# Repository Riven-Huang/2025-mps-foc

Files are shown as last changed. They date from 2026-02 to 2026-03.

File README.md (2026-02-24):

# MPS-FOC 开源电机驱动

<div align="center">



[]()
[]()

**基于 TI C2000 F28002x 的三环 FOC 电机驱动**

</div>

## 📋 项目简介

本项目依托于 2025 MPS“智驱未来”机器人芯动力设计挑战赛 并使用MPS旗下系列IC制作电源、驱动和传感器，使用 TI TMS320F280023C 单片机的开源 FOC（磁场定向控制）电机驱动项目。支持有传感器（磁编码器）FOC 闭环控制，提供电流环、速度环、位置环三环级联控制。

目前借助开环电压模式已实现 **速度环** 和 **位置环** 的运行，经验证控制效果良好。在硬件设计上，有预留好供 **电流环** 使用的A、C相电流采样，代码中同样给出了参数整定方法与完整架构。不过若只想复现该项目测试视频中的效果，可以将其电流环删去，简要复现。

### 🔑 核心特性

- **FOC 算法**： Clarke/Park 变换 + SVPWM（带3次谐波注入）
- **三环控制**：电流环(20kHz) → 速度环(2kHz) → 位置环(1kHz)
- **位置传感器**：MA600 磁编码器（13-bit分辨率，4096 PPR）
- **功率驱动**：MP6539 三相 MOSFET 预驱动
- **接口丰富**：支持 UART 调试（可扩展 CAN/RS485）

---

## 🏗️ 硬件说明

### 📦 硬件实物图

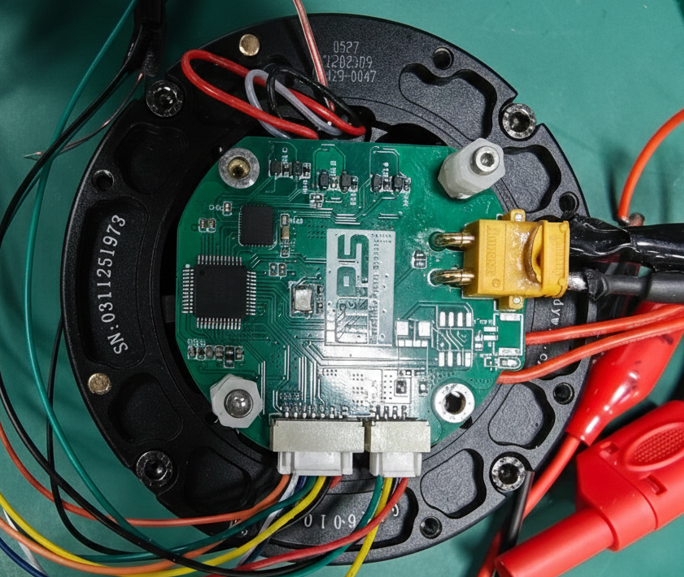
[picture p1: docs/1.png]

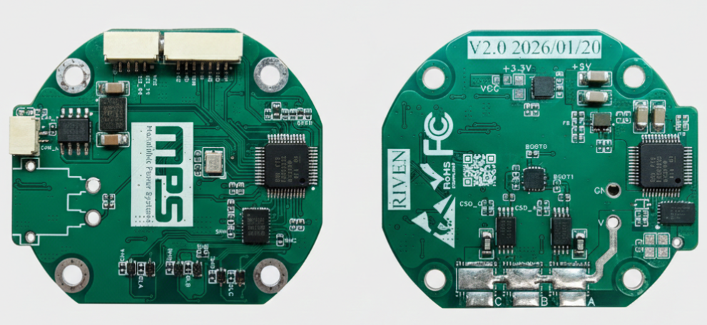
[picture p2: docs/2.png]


### 📦 主要器件

| 器件 | 型号 | 说明 |
|---|---|---|
| MCU | TMS320F280023C | 32-bit C2000，100MHz 主频 |
| 驱动IC | MP6539 | 三相无刷电机预驱动 |
| 编码器 | MA600A | 磁编码器，13-bit 分辨率 |
| 功率MOS | BSC030N08NS5 | 低导通电阻 N-MOS |

### 🔌 引脚定义

```
PWM 输出:  EPWM1A (GPIO0) → A相
           EPWM2A (GPIO2) → B相
           EPWM3A (GPIO4) → C相

电流采样:  ADCINA11 (Ia)
           ADCINB7 (Ic)
           ADCINA5 (Vbus)

MA600A编码器:   GPIO33 (CS)
               GPIO32 (CLK)
               GPIO24 (MOSI)
               GPIO16 (MISO)

控制信号:  GPIO31 (nSLEEP)
           GPIO12 (FAULT)
```

### 📐 电气参数

| 参数 | 数值 |
|---|---|
| 输入电压 | 48V±5% DC |
| 峰值电流 | 4A |
| 持续电流 | 1.5A |
| PWM 频率 | 20kHz |
| 最大转速 | 4000 RPM |

---

## 📂 目录结构

```
mps-foc-opensource/
├── program/                    # 固件源码
│   ├── foc_main.c              # 主程序 + 中断控制
│   ├── app/
│   │   ├── foc_core.c/h        # FOC 核心算法
│   │   ├── soft_spi_ma600.c/h # 磁编码器软SPI驱动
│   │   └── bsp_tim.c/h        # 定时器驱动
│   ├── device/                 # TI C2000 器件库
│   ├── cmd/                    # 链接器配置文件
│   └── c2000.syscfg           # TI SysConfig 配置
├── circuit/                    # 硬件设计
│   ├── PCB_MPS-FOC_V2.1.pdf   # PCB 丝印图
│   └── SCH_MPS-FOC_V2.1.pdf  # 原理图
├── manufacture/                # 制造文件 (Gerber)
│   └── MPS-FOC_V2.1/          # 嘉立创可直接下单
├── LICENSE                     # 许可证文件
└── README.md                   # 本文件
```

---

## 💻 软件说明

### 🌀 三环控制逻辑

| 环 | 频率 | 输入 | 输出 | 作用 |
|----|---|---|---|---|
| 电流环 | 20kHz | Id/Iq 误差 | Vd/Vq | 快速响应，抑制电流波动 |
| 速度环 | 2kHz | 速度误差 | Iq_Ref | 稳态精度，动态响应 |
| 位置环 | 1kHz | 位置误差 | Speed_Ref | 位置跟踪，高精度控制 |

### ⚙️ 参数配置

在 `foc_main.c` 中修改以下参数：

#### 1. 电机参数

```c
// 电机参数
#define POLE_PAIRS      14      // 极对数
#define PWM_PERIOD      2500    // PWM周期 (20kHz @ 50MHz)
#define GEAR_RATIO      8.0f    // 减速比
```

#### 2. 电流环参数 (根据带宽计算)

电流环使用 PI 控制器，参数可根据 desired bandwidth 自动计算：

```c
// 电机参数
float control_freq = 20000;              // 控制频率 20kHz
float singlephase_R = 1.45f/2.0f;       // 单相电阻 (Ω)
float singlephase_L = 0.823f/2.0f/1000; // 单相电感 (H)

// 电流环带宽 (建议设为采样频率的1/10~1/20，即 1kHz~2kHz)
float current_bandwidth = 1000.0f;       // 电流环带宽 (Hz)

// PI 参数计算公式:
// Ti = L/R (积分时间常数)
// Kp = L * ωc (比例增益)
// Ki = R * ωc (积分增益)
// 其中 ωc = 2π * fc (交叉频率)
float current_Ti = singlephase_L / singlephase_R;       // 积分时间
float current_wc = 2.0f * 3.14159f * current_bandwidth; // 交叉频率
float current_Kp = singlephase_L * current_wc;          // 比例增益
float current_Ki = singlephase_R * current_wc;          // 积分增益
```

#### 3. 速度环/位置环参数

```c
// 速度环 (2kHz)
pid_spd.Kp = 0.1f; pid_spd.Ki = 0.005f; pid_spd.OutMax = VOLTAGE_LIMIT;

// 位置环 (1kHz)
pid_pos.Kp = 20.0f; pid_pos.Ki = 0.0f; pid_pos.OutMax = 500.0f;
```

> **提示**: 调整 `current_bandwidth` 可改变电流环响应速度。带宽越高，响应越快，但对噪声越敏感。

---

## 🚀 快速开始

### 🛠️ 开发环境

- **IDE**: TI CCS (Code Composer Studio) 12.x
- **SDK**: C2000Ware 6.00.01+
- **编译器**: TI C2000 Clang v3.x

### 🔌 硬件连接

```
┌─────────────────┐         ┌─────────────────┐
│   FOC 驱动板    │         │    电机模组     │
│                 │         │                 │
│  A+  ───────────┼─────────▶│   A相 (橙)     │
│  B+  ───────────┼─────────▶│   B相 (黄)     │
│  C+  ───────────┼─────────▶│   C相 (绿)     │
│  GND ──────────┼─────────▶│   GND (黑)     │
│                 │         │                 │
└─────────────────┘         └─────────────────┘
```

### 🎮 运行步骤

1. **上电初始化**
   - 系统自动进行电流零点校准（1秒）
   - 校准完成后进入编码器对齐阶段（1秒）
   - 对齐完成后进入闭环控制

2. **选择控制模式**

   | 模式 | Control_Mode 值 | 说明 |
   |------|-----------------|------|
   | 力矩模式 | 0 | 直接给定电压 |
   | 速度模式 | 1 | 给定目标转速 |
   | 位置模式 | 2 | 给定目标角度 |

3. **调试接口**

   通过 CCS 调试窗口修改变量：

   ```c
   Run_Flag = 1;           // 启动 PWM 输出
   Control_Mode = 1;       // 切换到速度模式
   User_Speed_Ref = 500;  // 设置目标转速 500 RPM
   ```

### 🔧 调试步骤（快速检查表）

| 步骤 | 内容 | 验证方法 |
|:---:|---|---|
| 1 | **硬件检查** | 测 3.3V / 12V / 48V / LED正常亮起 |
| 2 | **程序烧录** | 检查ADC中断，定时器中断能否正常运行 |
| 3 | **PWM 测试** | 示波器查看三相 PWM + 死区时间 |
| 4 | **ADC 校准** | 断开电流，零点应在 2048 附近 |
| 5 | **编码器** | 旋转电机，观察角度变化 |
| 6 | **开环电压模式** | `Control_Mode=0`，`User_Iq_Ref=1` 电机转动|
| 7 | **速度环** | `Control_Mode=1`，`User_Speed_Ref=100` |
| 8 | **位置环** | `Control_Mode=2`，`User_Pos_Ref=3.14` |

### 调试变量速查

```c
Run_Flag = 1;           // 1=开启PWM, 0=关闭
Control_Mode = 0;       // 0=电压/1=速度/2=位置
User_Iq_Ref = 1.0f;    // 电压模式输入 (V)
User_Speed_Ref = 100;   // 速度模式输入 (RPM)
User_Pos_Ref = 3.14;   // 位置模式输入 (Rad)
MA600_dir = 1.0f;      // 编码器方向，取反改 -1
```

### 常见问题

| 问题 | 解决方法 |
|---|---|
| 电机不转/异响 | 交换 A/B/C 相序 |
| 只朝一个方向转 | `MA600_dir = -1` |
| 电流采样异常 | 检查运放偏置、调整 `CURRENT_SCALE` |
| 速度波动大 | 调小 `Speed_Filter_K` 或调整 PID |

---

## 📖 使用教程

### 电机参数整定

1. **电流环参数整定(暂无)**
   - 测试阶段用较小初值尝试
   - 测试完成后，用计算公式整定

2. **速度环参数整定**
   - 电流环稳定后，切换到速度模式
   - 给定小目标速度（如 100 RPM）
   - 整定方法同上
   - 推荐初值：Kp=0.1, Ki=0.005

3. **位置环参数整定**
   - 最后整定位置环，仅用Kp

### 🔧 常见问题

**Q1: 电机不转，有异响**

> 检查：
> 1. 尝试更换A,B,C三相相序任意两根
> 2. 尝试修改编码器极性
> 3. PWM 输出是否正常

---

## 📄 许可证

本项目采用 [CERN-OHL-S v2](LICENSE) 开源许可证。

CERN-OHL-S 是硬件开源的标准许可证，要求衍生作品必须以相同条款开源。

---

## 📧 联系我们

- 问题反馈：GitHub Issues
- 邮箱：banzang_coder@163.com

---

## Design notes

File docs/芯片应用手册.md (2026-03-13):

# MPS-FOC 芯片应用手册

## 1. 项目评审结论

当前项目已经形成完整的“电源链路 + 驱动链路 + 角度反馈链路”：`48V -> 12V -> 5V -> 3.3V` 分级供电稳定，`MP6539B` 三相驱动链路可正常出 PWM，`MA600A` 角度反馈已接入 FOC 主环，速度环和位置环可运行，电流环参数也已经在代码中按带宽法计算并初始化。对比赛场景来说，这套方案的优势是启动快、可复现性高、展示稳定。

---

## 2. 本项目中的 MPS 芯片分工

1. `MA600A`：电机角度反馈（FOC 位置基准）
2. `MP6539B`：三相栅极驱动（驱动 6 颗外置 MOS）
3. `MP4583`：`48V -> 12V` 高压 Buck
4. `MPM3632S`：`12V -> 5V` Buck 电源模块
5. `MP20051`：`5V -> 3.3V` 低噪声 LDO
6. `MIE1W0505`：隔离 `5V -> ISO_5V`（通信隔离侧）

---

## 3. 分芯片应用说明（含数据与项目落地）

### 3.1 MA600A（位置传感）

MA600A 是本项目 FOC 的角度基准，固件在 `20kHz` 中断里通过软 SPI 读角度（`MA600_ReadRaw_Fast()`），并用 `theta = raw * (2π/65536)` 转机械角，当前实现的角度量化步进是 `0.00009587 rad`（`0.00549°`）；再乘电机 `14` 极对得到电角度，等效电角分辨率 `0.0769°`。这个分辨率级别在低速下能明显减少 Park 变换输入抖动，速度环/位置环会更平顺，尤其是小角度定位时更容易“贴着目标走”。

### 3.2 MP6539B（3 相栅极驱动）

驱动芯片承担“把 MCU 的控制量变成三相功率级开关动作”的核心角色，项目中由 EPWM 输出 `6` 路互补 PWM（A/B/C 三相上下桥）送入 MP6539B，再去驱动外置 `6` 颗 BSC030N08NS5；按器件数据（同系列口径）可覆盖 `8V~100V` 驱动电压范围，栅极驱动能力约 `IOH=800mA`、`IOL=1A`、`6` 路驱动通道。固件里 `nSLEEP` 由 GPIO 直接控制，上电后先使能再放 PWM，且 MCU 侧已配置死区：`deadband=100` 计数（`100MHz` TBCLK 下约 `1us`），这套配置对比赛调试非常友好，既能快速跑起来，也有明确保护边界。

### 3.3 MP4583（48V -> 12V 高压 Buck）

MP4583 把母线 `48V` 先降到 `12V`，直接把高压与控制/接口电源域隔开；发布版原理图参数是 `R6=180k`、`R5=12.58k`、`L6=22uH`，按常见 FB 公式 `Vout = VFB * (1 + Rtop/Rbot)`、`VFB≈0.8V` 计算：`Vout ≈ 0.8*(1+180/12.58)=12.25V`，与目标 12V 一致。把最高压这一级先处理掉后，后级 5V/3.3V 电源设计压力会明显降低，比赛现场电池波动时系统也更稳。

### 3.4 MPM3632S（12V -> 5V 电源模块）

MPM3632S 是中间母线电源，承担全板 `5V` 供电主力；器件本身是集成电感降压模块，典型能力 `4V~18V` 输入、`3A` 输出、`2.2MHz` 开关频率。项目原理图给出的分压是 `R35=43k`、`R36=8.2k`，按 `VFB≈0.8V` 计算得到 `Vout ≈ 4.99V`，与 5V 目标精确对齐。这个模块把外围设计复杂度压低了，硬件迭代时间更短，适合比赛周期内快速出稳定板。

### 3.5 MP20051（5V -> 3.3V LDO）

MP20051 是控制侧“末级净化电源”，给 MCU 与逻辑域提供更干净的 3.3V；器件参数层面有 `1A` 输出能力、`PSRR=63dB@1kHz`、`Dropout=140mV@1A`、噪声约 `13uVrms`，在 FOC 的 ADC 采样与角度处理场景里很实用。原理图分压为 `R42=75k`、`R41=24k`，按 `Vout = 0.8*(1+75/24)` 可得约 `3.3V`。此外 LDO 热设计可直接按 `P=(Vin-Vout)*Iout` 估算，例如 `5V->3.3V`、`0.2A` 时约 `0.34W`，比赛中按这个量级预留散热即可。

### 3.6 MIE1W0505（隔离电源）

MIE1W0505 给 CAN 隔离侧提供独立 `ISO_5V`，把功率地噪声和通信地做物理隔离；从型号可直接看出是 `5V->5V`、`1W` 隔离电源，折算输出电流上限约 `Iout_max = 1W / 5V = 0.2A`。这个隔离电源在电机大电流开关噪声环境下非常关键，通信链路不容易被功率回流“带脏”，长时间演示时总线稳定性明显更好。

---

## 4. 开关电源参数怎么计算（本项目可直接套用）

### 4.1 输出电压分压

```text
Vout = VFB * (1 + Rtop / Rbot)
```

1. `MP4583`（48V->12V）：`Rtop=180k, Rbot=12.58k`，`Vout≈12.25V`
2. `MPM3632S`（12V->5V）：`Rtop=43k, Rbot=8.2k`，`Vout≈4.99V`

### 4.2 占空比一阶估算

```text
D ≈ Vout / Vin
```

1. `48V -> 12V`：`D≈0.25`
2. `12V -> 5V`：`D≈0.417`

### 4.3 电感纹波电流估算（Buck）

```text
ΔIL = (Vin - Vout) * D / (L * fsw)
```

以 MP4583 级举例：若 `Vin=48V, Vout=12V, D=0.25, L=22uH`，假设 `fsw=500kHz`，则 `ΔIL≈0.82A`。这个值可用于反推电感和输出电容选型。

### 4.4 输出电容估算（纹波约束）

```text
Cout >= ΔIL / (8 * fsw * ΔVout)
```

延续上例，若目标纹波 `ΔVout=50mV`，则 `Cout>=4.1uF`（工程上通常会留余量并并联低 ESR 电容）。

### 4.5 LDO 功耗估算（MP20051）

```text
P_LDO = (Vin - Vout) * Iout
```

`5V -> 3.3V`、`Iout=0.2A` 时约 `0.34W`，可作为热设计和封装温升评估输入。

---

## 5. 代码中的关键实参（和芯片联动）

1. 控制频率：`20kHz`（`PWM_PERIOD=2500`，中心对齐）
2. 电流环带宽：`1000Hz`
3. 电流环 PI（按代码电机参数计算）：`Kp≈2.586`，`Ki≈4555`
4. 速度计算常数：`190985.9`（`20kHz * 60 / 2π`）
5. 总线电压换算：`Vbus = 0.01933594 * ADC`

这些值已经在工程中闭环使用，手册中的芯片参数计算与控制参数是同一套口径。

---

## 6. 评审备注（建议在比赛材料中说明）

项目工程文件中存在“同一电源网络的历史参数痕迹”（如原理图 PDF 与工程库可见不同分压组合），但两套参数都围绕 `12V/5V/3.3V` 目标设计。比赛提交前建议以“实板丝印+实测电压+BOM导出”为最终口径，把 `README`、`应用手册`、`答辩 PPT` 三处参数统一，评委追问时会更稳。

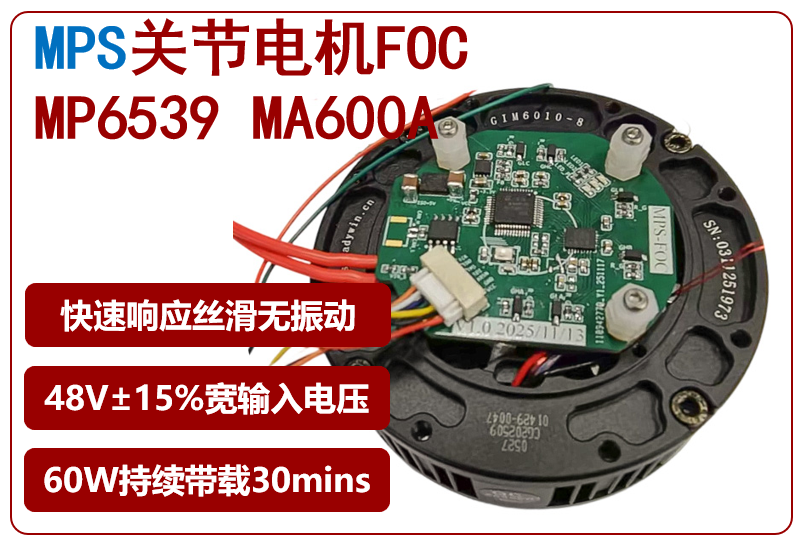
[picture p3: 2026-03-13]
产品图.png

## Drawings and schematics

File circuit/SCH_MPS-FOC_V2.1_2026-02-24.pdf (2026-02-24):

# 高压BUCK 48V->12V

TMS320F280023CPTS | BUCK 12V->5V

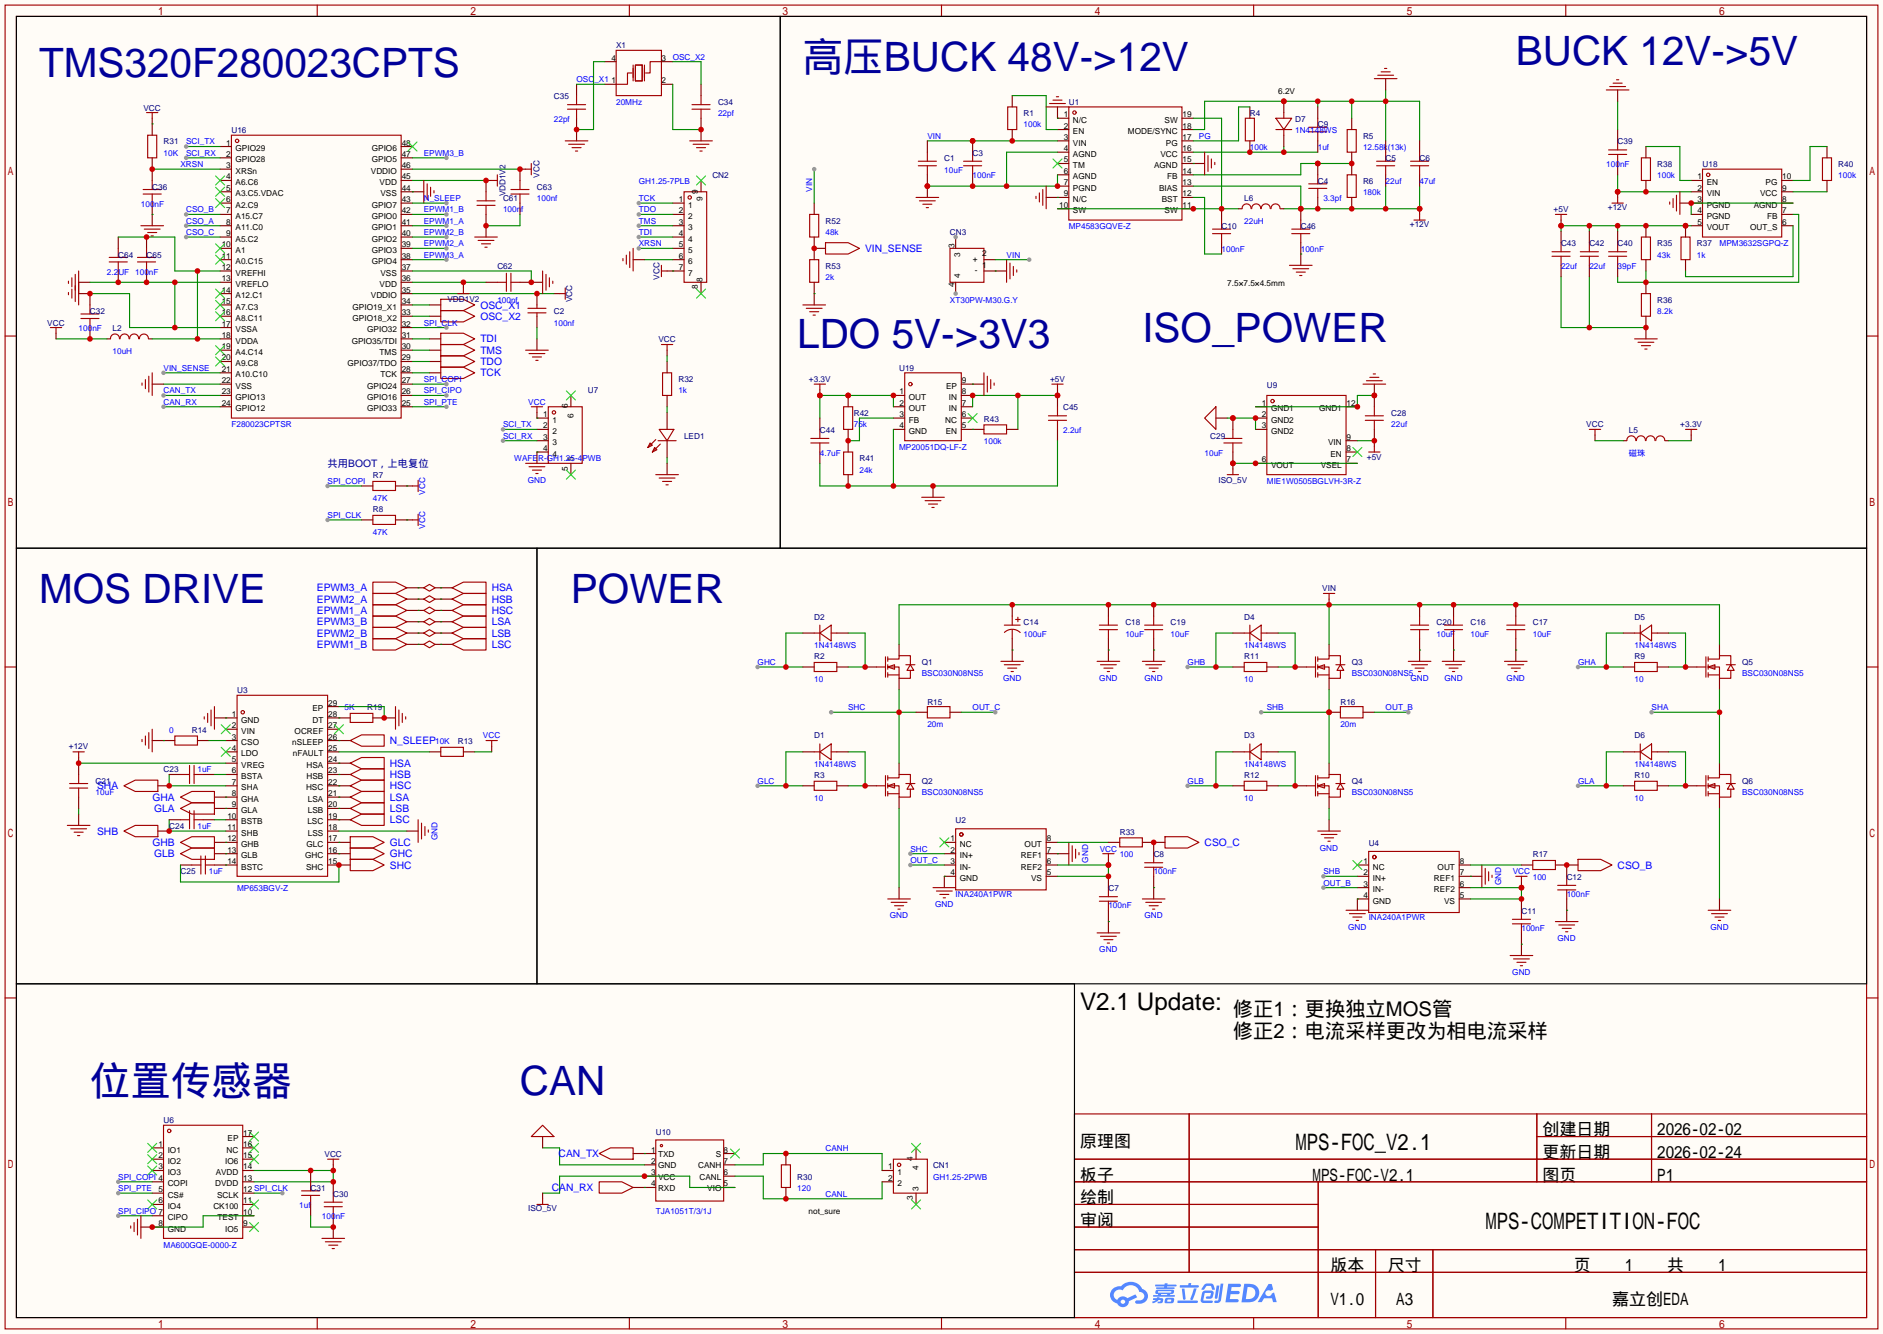
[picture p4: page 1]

TEST 10 CK100 11 SCLK 12 DVDD 13 AVDD 14 IO6 15 NC 16 EP 17

原理图 | MPS-FOC_V2.1 | 创建日期 | 2026-02-02

更新日期 | 2026-02-24

板子 | MPS-FOC-V2.1 | 图页 | P1
绘制 | | MPS-COMPETITION-FOC
审阅

V1.0 | A3 | 嘉立创EDA

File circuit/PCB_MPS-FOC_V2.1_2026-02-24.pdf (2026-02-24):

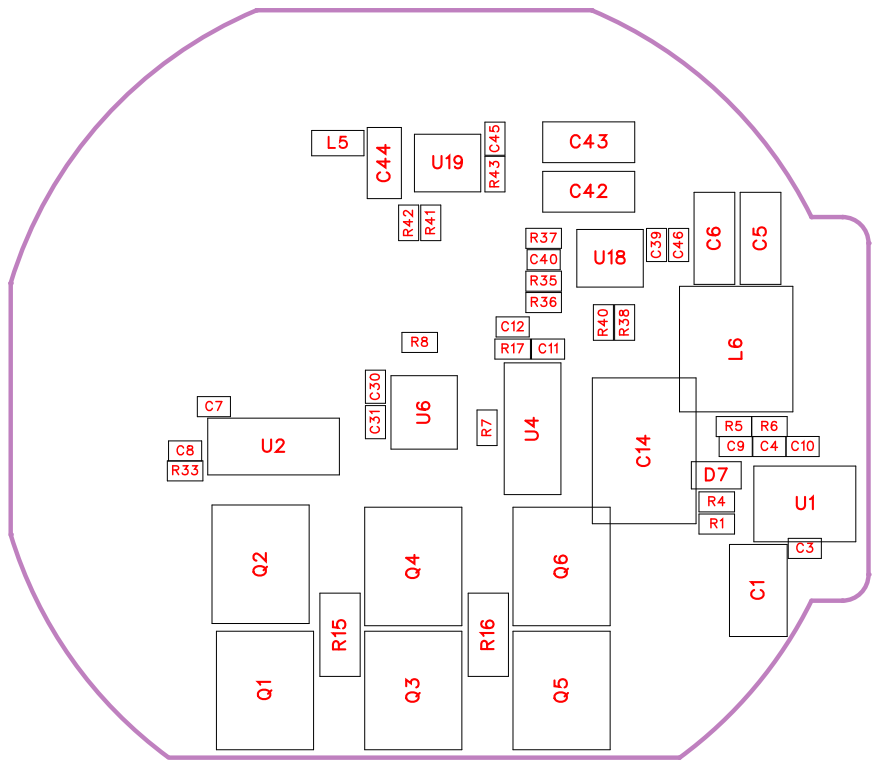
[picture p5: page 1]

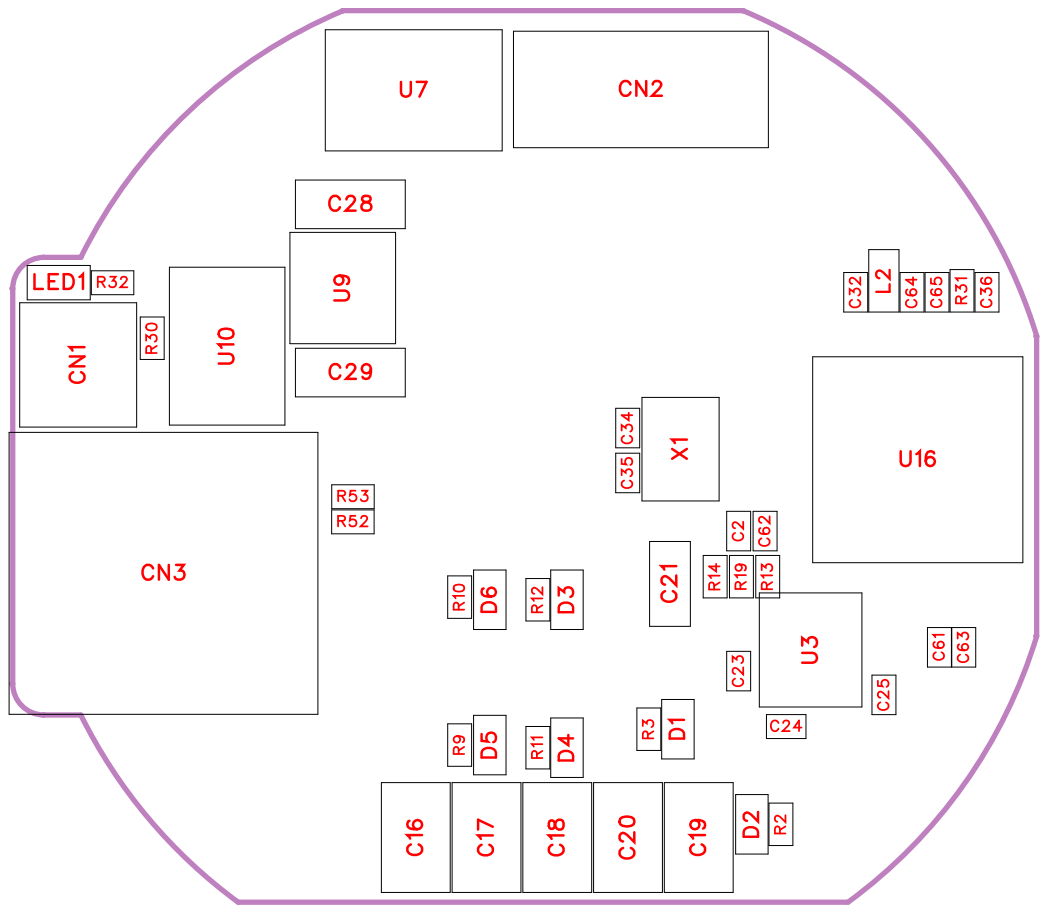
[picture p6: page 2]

No. | Quantity | Comment | Designator | Footprint | Value | Manufacturer Part | Manufacturer | Supplier Part | Supplier
1 | 6 | 10uF | C1,C16,C17,C18,C19,C20 | C1210 | 10uF | FS32X106K1 01EGG | PSA(信昌电 陶) | C5156756 | LCSC
2 | 1 | 100nf | C2 | C0402 | 100nf | 0402CG120J 500NT | FH(风华) | | LCSC
3 | 12 | 100nF | C3,C7,C8,C10,C11,C12,C3 0,C32,C36,C39,C46,C65 | C0402 | 100nF
4 | 1 | 3.3pf | C4 | C0402 | 3.3pf
5 | 4 | 22uf | C5,C28,C42,C43 | C1206 | 22uf | CL31A106KB HNNNE | SAMSUNG( 三星) | | LCSC
6 | 1 | 47uf | C6 | C1206 | 47uf | CL31A106KB HNNNE | SAMSUNG( 三星) | | LCSC
7 | 2 | 1uf | C9,C31 | C0402 | 1uf
8 | 1 | 100uF | C14 | CAP-TH_BD 10.0-P5.00-D 0.6-FD_H16. 0 | 100uF | ERA100V100 M10X16 | JIERR(捷而 瑞) | C49256825 | LCSC
9 | 1 | 10uF | C21 | C0805 | 10uF | CGA0805X5 R106K250M T | HRE(芯声) | C6119887 | LCSC
10 | 3 | 1uF | C23,C24,C25 | C0402 | 1uF
11 | 1 | 10uF | C29 | C1206 | 10uF | CL31A106KB HNNNE | SAMSUNG( 三星) | C13585 | LCSC
12 | 2 | 22pf | C34,C35 | C0402 | 22pf
13 | 1 | 39pF | C40 | C0402 | 39pF
14 | 1 | 4.7uF | C44 | C0805 | 4.7uF | CL21A475KA QNNNE | SAMSUNG( 三星) | C1779 | LCSC
15 | 1 | 2.2uf | C45 | C0402 | 2.2uf
16 | 3 | 100nf | C61,C62,C63 | C0402 | 100nf
17 | 1 | 2.2UF | C64 | C0402 | 2.2UF
18 | 1 | GH1.25-2PW B | CN1 | CONN-TH_2 P-P1.25_XU NPU_WAFE R-GH1.25-2P WB | | GH1.25-2PW B | XUNPU(讯普 ) | C3029377 | LCSC
19 | 1 | GH1.25-7PL B | CN2 | CONN-SMD_ 7P-P1.25_X UNPU_WAF ER-GH1.25-7 PLB | | GH1.25-7PL B | XUNPU(讯普 ) | C3029373 | LCSC
20 | 1 | XT30PW-M3 0.G.Y | CN3 | CONN-TH_X T30PW-M | | XT30PW-M3 0.G.Y | AMASS(艾迈 斯) | C431092 | LCSC
21 | 7 | 1N4148WS | D1,D2,D3,D4,D5,D6,D7 | SOD-323_L1 .7-W1.3-LS2. 5-FD | | 1N4148WS | R+O(宏嘉诚) | C7420319 | LCSC
22 | 1 | 10uH | L2 | L0603 | 10uH
23 | 1 | 磁珠 | L5 | L0603 | | 磁珠 | Sunlord(顺络 ) | C1002 | LCSC

24 | 1 | 22uH | L6 | IND-SMD_L6 .0-W6.0 | 22uH | FNR6045S22 0MT | cjiang(长江微 电) | C168080 | LCSC
25 | 1 | LTST-C191K SKT | LED1 | LED0603-RD -YELLOW | | LTST-C191K SKT | LITEON(光宝 ) | C125100 | LCSC
26 | 6 | BSC030N08 NS5 | Q1,Q2,Q3,Q4,Q5,Q6 | nmos qfn封装
27 | 5 | 100k | R1,R4,R38,R40,R43 | R0402 | 100k
28 | 6 | 10 | R2,R3,R9,R10,R11,R12 | R0402 | 10
29 | 1 | 12.58k(13k) | R5 | R0402 | 12.58k(13k)
30 | 1 | 180k | R6 | R0402 | 180k
31 | 2 | 47K | R7,R8 | R0402 | 47K
32 | 2 | 10K | R13,R31 | R0402 | 10K
33 | 1 | 0 | R14 | R0402 | 0
34 | 2 | 20m | R15,R16 | R1206 | 20m | JER1206F1R 020 | JIERR(捷而 瑞) | C46634440 | LCSC
35 | 2 | 100 | R17,R33 | R0402 | 100 | 0402WGF20 03TCE | UNI-ROYAL( 厚声) | | LCSC
36 | 1 | 5K | R19 | R0402 | 5K
37 | 1 | 120 | R30 | R0402 | 120
38 | 2 | 1k | R32,R37 | R0402 | 1k
39 | 1 | 43k | R35 | R0402 | 43k
40 | 1 | 8.2k | R36 | R0402 | 8.2k
41 | 1 | 24k | R41 | R0402 | 24k
42 | 1 | 75k | R42 | R0402 | 75k
43 | 1 | 48k | R52 | R0402 | 48k
44 | 1 | 2k | R53 | R0402 | 2k
45 | 1 | MP4583GQV E-Z | U1 | QFN-19_L5.0 -W3.0_CD45 83GQVE | | MP4583GQV E-Z | MPS(芯源) | C29073231 | LCSC
46 | 2 | INA240A1P WR | U2,U4 | TSSOP-8_L4 .4-W3.0-P0.6 5-LS6.4-BL | | INA240A1P WR | TI(德州仪器) | C93965 | LCSC
47 | 1 | MP653BGV-Z | U3 | QFN-28_L5.0 -W4.0-P0.50-TL-EP3.7 | | MP653BGV-Z | MPS(芯源) | C5676243 | LCSC
48 | 1 | MA600GQE-0000-Z | U6 | WQFN-16_L 3.0-W3.0-P0. 50-BL-EP1.6 5 | | MA600GQE-0000-Z | MPS(芯源) | C18221548 | LCSC
49 | 1 | WAFER-GH1 .25-4PWB | U7 | CONN-SMD_ 4P-P1.25_X UNPU_WAF ER-GH1.25-4 PWB | | WAFER-GH1 .25-4PWB | XUNPU(讯普 ) | C3029379 | LCSC

50 | 1 | MIE1W0505 BGLVH-3R-Z | U9 | LGA-12_L4.0 -W5.0_MIE1 W0505BGLV H | | MIE1W0505 BGLVH-3R-Z | MPS(芯源 ) | C22419841 | LCSC
51 | 1 | TJA1051T/3/ 1J | U10 | SOIC-8_L4.9 -W3.9-P1.27-LS6.0-BL | | TJA1051T/3/ 1J | NXP(恩智浦 ) | C38695 | LCSC
52 | 1 | F280023CPT SR | U16 | LQFP-48_L7. 0-W7.0-P0.5 0-LS9.0-TL | | F280023CPT SR | TI(德州仪器 ) | C2879265 | LCSC
53 | 1 | MPM3632SG PQ-Z | U18 | ECLGA-10_L 3.0-W3.0-P0. 65-TL | | MPM3632SG PQ-Z | MPS(芯源 ) | C3187564 | LCSC
54 | 1 | MP20051DQ -LF-Z | U19 | QFN-8_L3.0-W3.0-P0.65-TL-EP2.5 | | MP20051DQ -LF-Z | MPS(芯源 ) | C134275 | LCSC
55 | 1 | 20MHz | X1 | CRYSTAL-S MD_4P-L3.2-W2.5-BL-2 | 20MHz | X322520MS B4SI | YXC(扬兴晶 振) | C9004 | LCSC

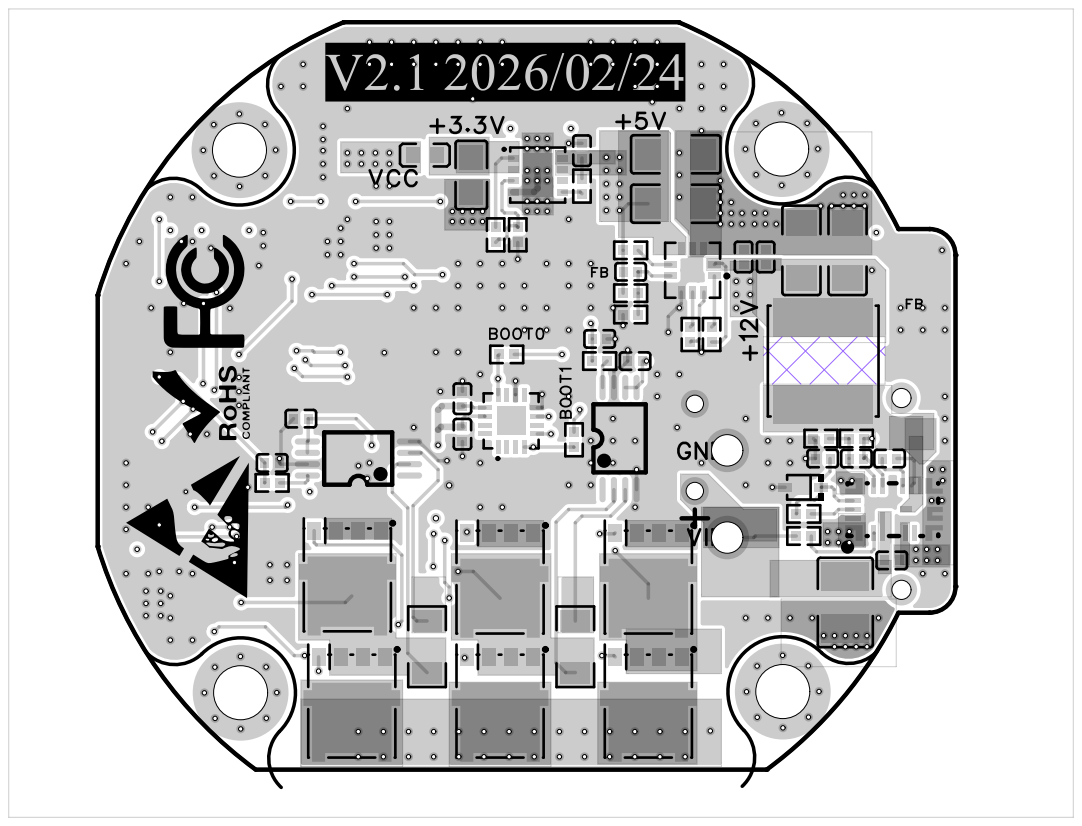
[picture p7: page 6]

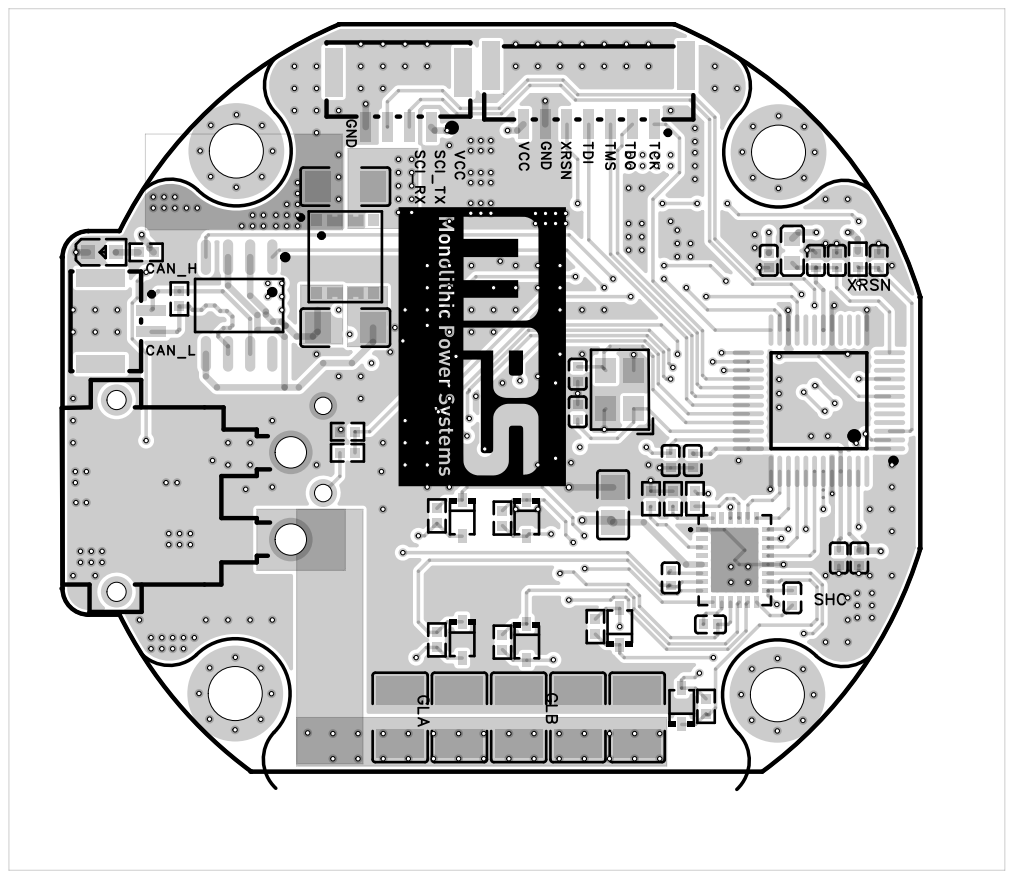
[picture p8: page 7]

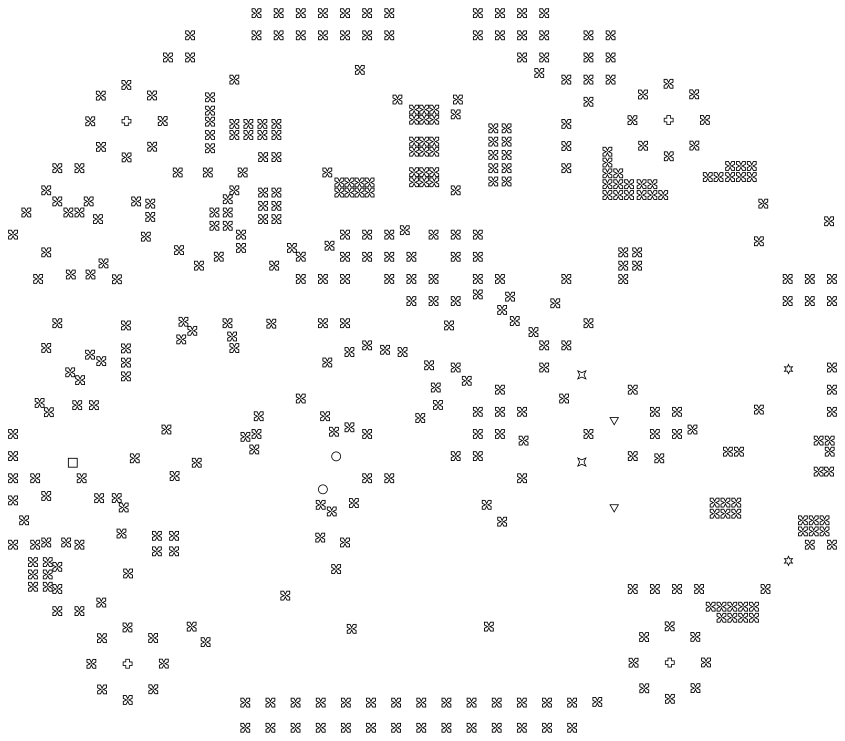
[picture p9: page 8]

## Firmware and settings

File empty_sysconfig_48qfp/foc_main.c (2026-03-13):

//#############################################################################
// FILE:   foc_main.c
// TITLE:  FOC Main Control Loop
//#############################################################################

//
// Included Files
//
#include "driverlib.h"
#include "device.h"
#include "board.h"
#include "c2000ware_libraries.h"

// user included Files
#include "foc_core.h"
#include "soft_spi_ma600.h"
#include <math.h>

// --- 宏定义 ---
#define PI              3.1415926535f
#define TWO_PI          6.283185307f
#define POLE_PAIRS      14.0f   // 极对数
#define PWM_PERIOD      2500    // 20kHz
#define CURRENT_SCALE   0.012207f

#define VOLTAGE_LIMIT   6.0f

// --- 全局控制对象 ---
FOC_State       foc;
PID_Controller  pid_id;
PID_Controller  pid_iq;
PID_Controller  pid_spd;
PID_Controller  pid_pos;

// --- 状态机 ---
enum {
    STATE_CALIB_CURRENT = 0,
    STATE_ALIGN_ENCODER,
    STATE_CLOSED_LOOP,
    STATE_ERROR
} Sys_State = STATE_CALIB_CURRENT;

// --- 控制模式定义 ---
enum {
    CTRL_MODE_CURRENT = 0, // 纯力矩模式
    CTRL_MODE_SPEED,       // 速度模式
    CTRL_MODE_POSITION     // 位置模式
};

// --- 变量 ---
int   calib_cnt = 0;
float offset_Ia = 0.0f, offset_Ib = 0.0f;
float align_angle_offset = 0.0f; // 机械角度零点偏差
uint16_t loop_cnt = 0;           // 分频计数器

// --- 调试与观测变量 (全局) ---
uint16_t Ia_Raw = 0; // 定义在全局，方便在 Expressions 窗口观察
uint16_t Ib_Raw = 0;
uint16_t Ic_Raw = 0; 
uint16_t Vbus_Raw = 0;
float    raw_theta_mech = 0.0f;
float    MA600_dir = -1.0f;
static float old_theta_mech = 0.0f; // 用于测速

// --- 电机参数 ---
float control_freq = 20000;
float singlephase_R = 1.45f/2.0f;
float singlephase_L = 0.823f/2.0f/1000;

// --- 用户控制接口 ---
volatile int Control_Mode = CTRL_MODE_SPEED; 
volatile float User_Iq_Ref = 0.0f;    // Current Ref
volatile float User_Speed_Ref = 0.0f; // Speed Ref (RPM)
volatile float User_Pos_Ref = 0.0f;   // Position Ref (Rad)
volatile uint8_t Run_Flag = 1;  
volatile float Speed_Filter_K = 0.002f; 

float Speed_RPM_Raw = 0.0f;
float test_vq = 0;

    float Id_disp, Iq_disp; 

//
// Main
//
void main(void)
{
    Device_init();
    Device_initGPIO();
    Interrupt_initModule();
    Interrupt_initVectorTable();
    Board_init();
    C2000Ware_libraries_init();

    // --- user init ---
    MA600_SoftSPI_Init();

    // --- PID 参数初始化 ---
    // 1. 电流环 (10khz)
    pid_id.Kp = 0.00f;  pid_id.Ki = 0.0f; pid_id.OutMax = 5.0f; pid_id.OutMin = -5.0f; // 输出电压Vd,暂时未用
    pid_iq.Kp = 0.00f;  pid_iq.Ki = 0.0f; pid_iq.OutMax = 5.0f; pid_iq.OutMin = -5.0f; // 输出电压Vq
    // 2. 速度环 (2khz)
    pid_spd.Kp = 0.1f; pid_spd.Ki = 0.005f; pid_spd.OutMax = VOLTAGE_LIMIT; pid_spd.OutMin = -VOLTAGE_LIMIT; // 输出电流Iq
    // 3. 位置环 (1khz)
    pid_pos.Kp = 20.0f;  pid_pos.Ki = 0.0f;   pid_pos.OutMax = 500.0f; pid_pos.OutMin = -500.0f; // 输出速度RPM

    // 暂时先随便给一个，后续改成adc校准的
    foc.DC_Bus_V = 31.5f;

    // start the system
    GPIO_writePin(mp6539_nSLEEP,1);
    DEVICE_DELAY_US(500000);
    
    // init complete
    EINT;
    ERTM;

    //
    // IDLE loop. Just sit and loop forever (optional):
    //
    for(;;)
    {
        // --- screen ---
        GPIO_togglePin(LED1);
        DEVICE_DELAY_US(500000);
        // Enter code here
    }
}

// ADC 中断服务函数 (High Frequency Loop - e.g., 20kHz)
__interrupt void INT_IA_IC_ADCA_INT1_ISR(void) 
{

    // 1. 快速采样 (First-level)
    Ia_Raw = ADC_readResult(ADCARESULT_BASE, ADC_SOC_NUMBER0); 
    Ib_Raw = ADC_readResult(ADCCRESULT_BASE, ADC_SOC_NUMBER0);
    raw_theta_mech = MA600_dir * MA600_ReadAngle_SoftSPI(); 
    Vbus_Raw = ADC_readResult(ADCARESULT_BASE, ADC_SOC_NUMBER1);
    Ic_Raw = ADC_readResult(ADCCRESULT_BASE, ADC_SOC_NUMBER1);

    switch(Sys_State)
    {
        // --- 状态0: 电流零点校准 ---
        case STATE_CALIB_CURRENT:
            offset_Ia += Ia_Raw;
            offset_Ib += Ib_Raw;
            calib_cnt++;

            // 关断输出
            foc.Duty_A = 0.0f; foc.Duty_B = 0.0f; foc.Duty_C = 0.0f;

            if(calib_cnt >= 1000) {
                offset_Ia /= 1000.0f;
                offset_Ib /= 1000.0f;
                calib_cnt = 0;
                Sys_State = STATE_ALIGN_ENCODER; 
            }
            break;

        // --- 状态1: 编码器对齐 ---
        case STATE_ALIGN_ENCODER:
            // 强拖到电角度 0 度
            foc.Duty_A = 0.6f; 
            foc.Duty_B = 0.4f;
            foc.Duty_C = 0.4f;

            calib_cnt++;
            if(calib_cnt >= 20000) { // 1秒
                align_angle_offset = raw_theta_mech; 
                Sys_State = STATE_CLOSED_LOOP; 
            }
            break;

        // --- 状态2: 闭环控制 ---
        case STATE_CLOSED_LOOP:
            // [数据清洗]
            foc.Ia = ((float)Ia_Raw - offset_Ia) * CURRENT_SCALE;
            foc.Ib = -((float)Ib_Raw - offset_Ib) * CURRENT_SCALE; // ！！！电流定义方向一定要一样 ！！！

            // [角度处理]
            foc.Theta_Mech = raw_theta_mech - align_angle_offset;
            if(foc.Theta_Mech < 0) foc.Theta_Mech += TWO_PI; // 归一化到 0-2PI
            
            foc.Theta_Elec = foc.Theta_Mech * POLE_PAIRS;
            while(foc.Theta_Elec > TWO_PI) foc.Theta_Elec -= TWO_PI;
            while(foc.Theta_Elec < 0.0f)   foc.Theta_Elec += TWO_PI;

            // [速度计算] (简单微分)
            float diff = foc.Theta_Mech - old_theta_mech;
            if(diff > 3.14159f) diff -= 6.28f;       // 过零点处理
            else if(diff < -3.14159f) diff += 6.28f;
            
            // Speed (RPM) = diff(rad) * Fs * 60 / 2PI
            // Fs = 20000Hz.  K = 20000 * 9.549 = 190985.9
            Speed_RPM_Raw = diff * 190985.9f; 
            foc.Speed_RPM = (1.0f - Speed_Filter_K) * foc.Speed_RPM + (Speed_Filter_K * Speed_RPM_Raw);
            old_theta_mech = foc.Theta_Mech;

            FOC_Clarke(&foc);
            FOC_Park(&foc);

             // 简单的滤波用于显示
            Id_disp = 0.95f * Id_disp + 0.05f * foc.Id;
            Iq_disp = 0.95f * Iq_disp + 0.05f * foc.Iq;

            // [三环控制逻辑]
            loop_cnt++;if(loop_cnt>30)loop_cnt=0;

            float Vq_Target = 0.0f;

            switch(Control_Mode)
            {
                // --- 模式A: 位置模式 ---
                case CTRL_MODE_POSITION:
                    // 降频 20:1 (1kHz)
                    if(loop_cnt >= 20) 
                    {
                        loop_cnt = 0; // 复位计数
                        pid_pos.Ref = User_Pos_Ref;
                        pid_pos.Fbk = foc.Theta_Mech;
                        PID_Calc(&pid_pos);
                        
                        // 位置环输出 -> 速度环输入
                        pid_spd.Ref = pid_pos.Out; 
                        
                        // 级联执行速度环
                        pid_spd.Fbk = foc.Speed_RPM;
                        PID_Calc(&pid_spd);
                        foc.Iq_Ref = pid_spd.Out;
                    }
                    foc.Id_Ref = 0.0f; 
                    Vq_Target = pid_spd.Out; 
                    break;

                // --- 模式B: 速度模式 ---
                case CTRL_MODE_SPEED:
                    // 降频 10:1 (2kHz)
                    // 注意：这里使用取模运算或单独的计数逻辑，避免冲突
                    // 为了简单，直接复用 loop_cnt，但要小心位置模式切换过来时的初值
                    if(loop_cnt >= 10) 
                    {
                        loop_cnt = 0; 
                        
                        pid_spd.Ref = User_Speed_Ref; 
                        pid_spd.Fbk = foc.Speed_RPM;
                        PID_Calc(&pid_spd);         
                        foc.Iq_Ref = pid_spd.Out;
                    }
                    foc.Id_Ref = 0.0f; 
                    Vq_Target = pid_spd.Out;
                    break;

                // --- 模式C: 力矩模式 ---
                case CTRL_MODE_CURRENT:
                    // [修改] 此时变成了 "电压开环模式"
                    // User_Iq_Ref 现在被当作 Voltage Ref 使用
                    Vq_Target = User_Iq_Ref; 
                    break;   
            }

            if(Vq_Target > VOLTAGE_LIMIT) Vq_Target = VOLTAGE_LIMIT;
            if(Vq_Target < -VOLTAGE_LIMIT) Vq_Target = -VOLTAGE_LIMIT;

            foc.Vd = 0.0f;
            foc.Vq = Vq_Target;

            FOC_InvPark(&foc);
            FOC_SVPWM(&foc);
            break;
    }

    if(Run_Flag == 1)
    {
        EPWM_setCounterCompareValue(EPWM1_BASE, EPWM_COUNTER_COMPARE_A, (uint16_t)(foc.Duty_A * PWM_PERIOD));
        EPWM_setCounterCompareValue(EPWM2_BASE, EPWM_COUNTER_COMPARE_A, (uint16_t)(foc.Duty_B * PWM_PERIOD));
        EPWM_setCounterCompareValue(EPWM3_BASE, EPWM_COUNTER_COMPARE_A, (uint16_t)(foc.Duty_C * PWM_PERIOD));
    }else {
        EPWM_setCounterCompareValue(EPWM1_BASE, EPWM_COUNTER_COMPARE_A, 0);
        EPWM_setCounterCompareValue(EPWM2_BASE, EPWM_COUNTER_COMPARE_A, 0);
        EPWM_setCounterCompareValue(EPWM3_BASE, EPWM_COUNTER_COMPARE_A, 0);
    }


    ADC_clearInterruptStatus(ADCA_BASE, ADC_INT_NUMBER1);
    Interrupt_clearACKGroup(INTERRUPT_ACK_GROUP1);
}


//
// End of File
//

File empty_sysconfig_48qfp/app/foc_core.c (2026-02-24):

#include "foc_core.h"

// --- 增量式/位置式 PI 计算 ---
void PID_Calc(PID_Controller *pid)
{
    float error = pid->Ref - pid->Fbk;
    
    // 积分项
    pid->Ui += pid->Ki * error;
    
    // 积分抗饱和 (Anti-windup)
    if (pid->Ui > pid->OutMax) pid->Ui = pid->OutMax;
    else if (pid->Ui < pid->OutMin) pid->Ui = pid->OutMin;
    
    // 计算输出
    pid->Out = (pid->Kp * error) + pid->Ui;
    
    // 输出限幅
    if (pid->Out > pid->OutMax) pid->Out = pid->OutMax;
    else if (pid->Out < pid->OutMin) pid->Out = pid->OutMin;
}

// --- Clarke 变换 (3相 -> 2相静止) ---
void FOC_Clarke(FOC_State *foc)
{
    foc->Ialpha = foc->Ia;
    foc->Ibeta  = (foc->Ia + 2.0f * foc->Ib) * 0.577350269f; // 1/sqrt(3)
}

// --- Park 变换 (2相静止 -> 2相旋转) ---
void FOC_Park(FOC_State *foc)
{
    float s = sinf(foc->Theta_Elec);
    float c = cosf(foc->Theta_Elec);
    
    foc->Id =  foc->Ialpha * c + foc->Ibeta * s;
    foc->Iq = -foc->Ialpha * s + foc->Ibeta * c;
}

// --- 反 Park 变换 (2相旋转 -> 2相静止) ---
void FOC_InvPark(FOC_State *foc)
{
    float s = sinf(foc->Theta_Elec);
    float c = cosf(foc->Theta_Elec);
    
    foc->Valpha = foc->Vd * c - foc->Vq * s;
    foc->Vbeta  = foc->Vd * s + foc->Vq * c;
}

// --- SVPWM (简单标准版) + 反Clarke变换 ---
// 将 Valpha, Vbeta 转换为 DutyA, DutyB, DutyC
void FOC_SVPWM(FOC_State *foc)
{
    // 使用简化的 SPWM + 3次谐波注入 (等效于 SVPWM)
    // 这种方法代码最少，适合入门，效果与标准7段SVPWM几乎一样
    
    // 1. 归一化 (假设最大电压矢量是 DC_Bus / sqrt(3))
    // 系数取决于你的母线电压采样是否准确，这里简化处理，直接用 Valpha/Vbeta 算占空比
    // 假设 Vd, Vq 输出范围是 -Vbus/2 到 +Vbus/2
    
    float v_bus = foc->DC_Bus_V;
    if(v_bus < 1.0f) v_bus = 12.0f; // 防止除0，默认12V
    
    float inv_vbus = 1.0f / v_bus;
    
    // 逆 Clarke 变换得到 Va, Vb, Vc (暂存)
    float Va = foc->Valpha;
    float Vb = (-0.5f * foc->Valpha) + (0.866025f * foc->Vbeta);
    float Vc = (-0.5f * foc->Valpha) - (0.866025f * foc->Vbeta);
    
    // 3次谐波注入 (零序分量注入) -> 扩展 15% 电压利用率
    float Vmin, Vmax, Vcom;
    
    if (Va < Vb) { Vmin = Va; Vmax = Vb; } else { Vmin = Vb; Vmax = Va; }
    if (Vc < Vmin) Vmin = Vc;
    if (Vc > Vmax) Vmax = Vc;
    
    Vcom = -0.5f * (Vmax + Vmin);
    
    // 加上注入电压并归一化到 0~1
    foc->Duty_A = ((Va + Vcom) * inv_vbus) + 0.5f;
    foc->Duty_B = ((Vb + Vcom) * inv_vbus) + 0.5f;
    foc->Duty_C = ((Vc + Vcom) * inv_vbus) + 0.5f;
    
    // 最终限幅
    if(foc->Duty_A > 0.95f) foc->Duty_A = 0.95f; else if(foc->Duty_A < 0.05f) foc->Duty_A = 0.05f;
    if(foc->Duty_B > 0.95f) foc->Duty_B = 0.95f; else if(foc->Duty_B < 0.05f) foc->Duty_B = 0.05f;
    if(foc->Duty_C > 0.95f) foc->Duty_C = 0.95f; else if(foc->Duty_C < 0.05f) foc->Duty_C = 0.05f;
}

//
// End of File
//

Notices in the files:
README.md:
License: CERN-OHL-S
